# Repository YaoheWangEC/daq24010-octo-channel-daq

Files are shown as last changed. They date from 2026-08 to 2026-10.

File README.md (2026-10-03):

# DAQ24010 — 8 通道通用采集卡

> Octo-Channel Universal DAQ Card



---

## 简介 | Introduction

DAQ24010 是一款基于 **AT32F415** 的 8:1 通道通用采集卡，设计采集范围 ±5 V，前端搭配 12-bit 8 通道 ADC XADC128S022，支持通过 RS485 以 [Linux CLI 风味命令](https://github.com/YaoheWangEC/linux-cli-style-command-driver-framework) 控制采集，也可通过板载按键与 1.8" LCD 本地操作、显示波形。

该采集卡采样率支持 1 k ~ 200 k SPS，提供软件 / 电平 / 斜率触发方式，内置 TL431 基准实时反推 AVDD 用于电压换算。设备同时提供 EEPROM 供上位机持久化通道校正参数。

DAQ24010 is an 8:1 channel universal DAQ card based on the **AT32F415**, designed for a ±5 V acquisition range. With a 12-bit 8-channel ADC XADC128S022 on the front end, it is controlled over RS485 using [Linux CLI-style commands](https://github.com/YaoheWangEC/linux-cli-style-command-driver-framework), and can also be operated locally via on-board keys with waveform display on a 1.8" LCD.

The card supports 1 k ~ 200 k SPS and software / level / slope triggers, and features an on-board TL431 reference that derives AVDD at runtime for voltage conversion. An EEPROM lets the host persist per-channel calibration.

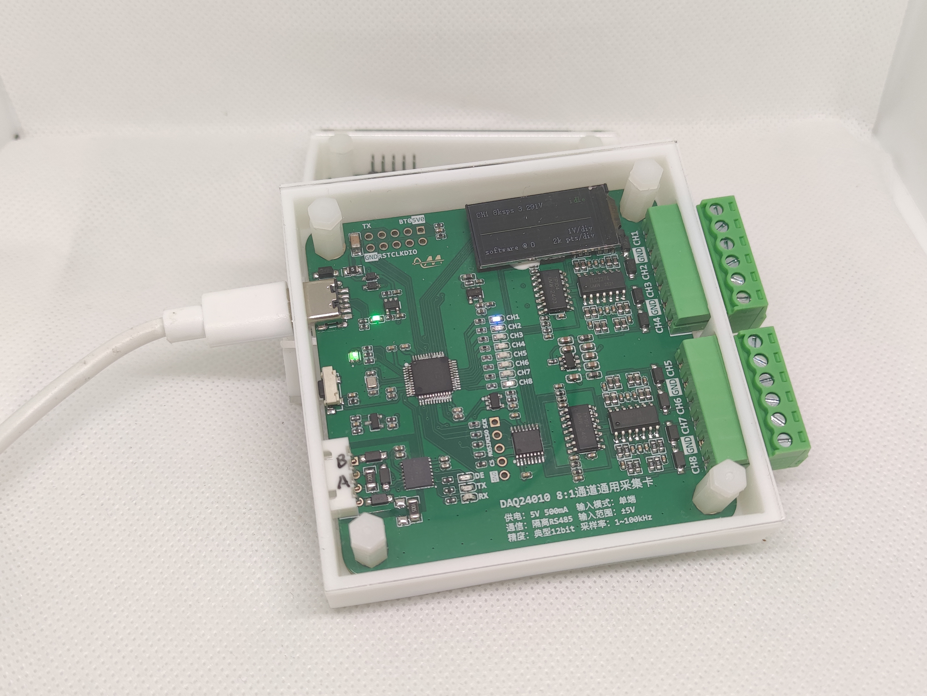
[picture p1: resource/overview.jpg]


> 视频演示：*待补充* ｜ 立创开源：*待补充*

## 主要参数 | Specifications

| 参数 | 值 | 备注 |
| --- | --- | --- |
| 供电 | USB 5 V，max. 500 mA | — |
| 输入通道 | 8 路单端 | 逻辑通道 1~8，可命令切换 |
| 输入范围 | 设计 ±5 V | 极限约 ±6.6 V |
| 采样率 | 1 k ~ 200 k SPS | 原始 100 k / 120 k / 200 k，N 档箱式平均降采样 |
| 触发 | 软件 / 电平 / 斜率 | `software`、`level±`、`slope±`，基于降采样输出 |
| 通信接口 | RS485 | 115200 8N1 |

---

## 快速上手 | Getting Started

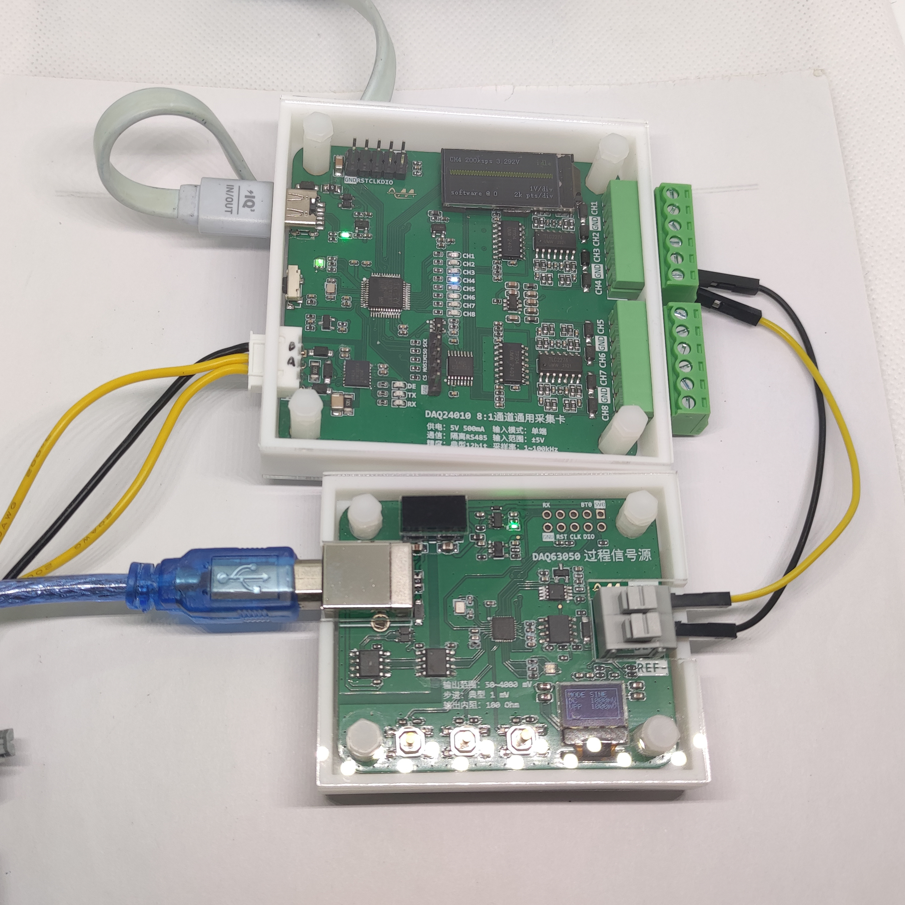
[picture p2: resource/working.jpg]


> 图中为 DAQ24010（待测）与 DAQ63050（信号源）联合测试场景。

### 1. 接线 | Wiring

| 接口名 | 接口形态 | 功能 | 备注 |
| --- | --- | --- | --- |
| 模拟输入 | 3.96 mm 间距插拔式接线端子 | 8 通道电压输入 | 单端，范围约 ±6.6 V |
| RS485 | XH254 4P | 控制 + 数据 | 115200 8N1，A/B 差分 |
| 供电 | USB Type-C | 电源输入 | 5 V，max. 500 mA |

### 2. 上电 | Power On

接通电源后，LCD 显示自检画面（设备名 / 产品名 / UID / `Hello World`），随后进入状态界面。上电约 1 s 后自动执行一次按键触发型采样并显示一次波形。RGB LED 指示采集状态：**空闲-绿 / 等待触发-蓝 / 采集中-红**。

### 3. 本地操作 | Local Control

| 按键 | 短按 | 长按 |
| --- | --- | --- |
| KEY | 软件触发一次采集并显示波形 | 切换下一通道（强制停止当前采集并重采） |

- 波形区：160 列 min/max 包络（前 8000 点，每列 50 点），网格为时间 2k pts/div、电压 1V/div。
- 状态栏显示：当前通道 / 采样率 / AVDD / 触发模式与阈值 / 采集状态。

### 4. RS485 控制 | RS485 Control

串口参数：**115200 bps, 8 data bits, 1 stop bit, no parity**

上电后发送 `lscmd` 可列出所有命令。DAQ24010 采用 [Linux CLI 风格](https://github.com/YaoheWangEC/linux-cli-style-command-driver-framework) 的 ASCII 文本协议，命令以 `\r\n` 结束，响应同样以 `\r\n` 结束，一问一答。

> 采样码值为 12-bit（`adc read` 以 4 字符紧凑 hex 回传，无分隔）。配置类命令（`status channel/rate/trigger`）仅允许在 **IDLE** 状态下执行，否则返回 `ERR: busy`。

#### 命令参考 | Command Reference

**`lscmd`** — 列出所有已注册命令

| 参数 | 说明 |
| --- | --- |
| `-h`, `--help` | 显示帮助 |

```
> lscmd
Supported commands:
  lscmd
  echo
  device
  eeprom
  reboot
  status
  adc
```

**`echo`** — 回显参数，用于测试通信链路

| 参数 | 说明 |
| --- | --- |
| `<text>` | 任意文本，多参数以空格拼接 |

```
> echo hello world
hello world
```

**`device`** — 读取设备名称与 MCU 96-bit 唯一 ID

无参数。

```
> device
Name  : DAQ24010 octo-channel-universal-daq
UID   : 12345678ABCDEF0012345678
```

**`reboot`** — 强制复位（拉低 NRST）

无参数。执行成功设备立即复位，无回包。

**`eeprom`** — 读写 AT24C02（256 B）

| 参数 | 说明 |
| --- | --- |
| `read <addr> [len]` | 读 `len` 字节（默认 1，上限 16），`addr+len ≤ 256` |
| `write <addr> <hex>` | 写紧凑 hex（偶数长度，上限 4 字节） |

```
> eeprom read 0 4
3F800000
> eeprom write 0 3F800000
OK
```

**`status`** — 查询或修改运行配置（修改仅 IDLE）

| 参数 | 说明 |
| --- | --- |
| *(无)* | 全量展示 tick/channel/raw_rate/dec_rate/trigger/state/avdd |
| `<field>` | 单项查询：`tick channel raw_rate rate trigger state avdd` |
| `channel <1..8>` | 设置逻辑通道 |
| `rate <rate>` | 设置降采样率（1000/2000/3000/4000/5000/6000/8000/10000/20000/30000/40000/50000/60000/100000/120000/200000） |
| `trigger <mode> [thr]` | 设置触发（`software level+ level- slope+ slope-`）与阈值码字 |

```
> status
tick     : 12345
channel  : 1
raw_rate : 200000
dec_rate : 8000
trigger  : software @ 0
state    : idle
avdd     : 3.291
> status channel 2
channel  : 2
> status rate 10000
raw_rate : 200000
dec_rate : 10000
```

**`adc`** — 采集控制与数据流

| 参数 | 说明 |
| --- | --- |
| *(无)* | 配置全量展示 + ringbuf 信息（buf_cnt/buf_cap/buf_full/overflow） |
| `status` | 仅返回采集状态（便于自动化读取） |
| `start` / `stop` | 开始 / 强制停止采集（stop 保留 ringbuf） |
| `rest` | 仅返回剩余样本数（便于轮询） |
| `read [n]` | 读出至多 n 个样本（默认/上限 128），4 字符紧凑 hex；不足则返回已有数据 |

```
> adc start
OK
> adc rest
1024
> adc read 128
0ABC0ABD0ABE...   # 每样本 4 hex 字符
```

> **采集模型**：设备采样写入 8192 点环形缓冲，**写满即自动停止**（不循环覆盖）。上位机需轮询 `adc rest` / `adc read` 排空。

---

## Python 驱动 | Python Driver

`software/driver/` 下提供纯驱动库 `daq24010.py`，封装上述 RS485 命令协议，内置电压换算、按通道校正与 EEPROM 持久化。

### 依赖 | Requirements

- Python 3.10+
- `pyserial`、`numpy`（自检绘图另需 `matplotlib`）

```
pip install pyserial numpy matplotlib
```

### 快速开始 | Quick Start

```python
from daq24010 import DAQ24010

with DAQ24010() as dev:                 # 自动嗅探串口（也可 DAQ24010('COM5')）
    print(dev.get_device_name(), dev.get_uid())

    dev.set_channel(1)
    dev.set_rate(2000)
    dev.set_trigger('level+', 0.0)      # 0V 电平上升沿触发（阈值单位: V）
    v = dev.capture(2000, timeout=5.0)  # 一键采集 2000 点, 返回电压 np.ndarray

# with 退出时 close(): 默认发 reboot 复位设备
```

### API 速查 | API Overview

| 区域 | 方法 |
| --- | --- |
| 生命周期 | `__init__(port=None, load_calib=True)` / `close(reboot=True)` / `with` |
| 设备信息 | `get_device_name()` / `get_uid()` |
| 状态查询 | `get_avdd()` / `get_status()` |
| 配置（仅 IDLE） | `set_channel`/`get_channel`、`set_rate`/`get_rate`、`set_trigger`/`get_trigger` |
| 采集控制 | `start` / `stop` / `get_state` / `get_acq_info` / `remaining` |
| 数据面 | `stream_read(n=128)` / `capture(n, timeout=5.0)` |
| 持久化 | `eeprom_read(addr, length)` / `eeprom_write(addr, data)` |
| 其他 | `reboot()` |

> 驱动对外以 **V** 为单位收发，内部换算为 ADC 码值。电压换算与校正、EEPROM 布局、采集吞吐等详细说明见 [`software/driver/README.md`](software/driver/README.md)。

---

## 许可证 | License

本项目由不同许可的组件构成：

- **应用代码**（`software/daq2401x-octo-channel-daq-f415cbt7/project/MDK_V5/daq2401x/` 下用户编写的采集逻辑、命令框架、LCD / 按键驱动等，以及 `software/driver/` 的 Python 驱动）以 [MIT License](LICENSE) 发布，版权归 [YaoheWangEC](https://github.com/YaoheWangEC)。
- **Artery BSP**（`libraries/drivers/`、`project/src/` 中 `wk_*.c`、`main.c` 模板等）版权归 Artery Technology，允许在与 Artery MCU 配合使用的场合复制和分发。
- **CMSIS-Core** 版权归 Arm Limited，遵循 Apache License 2.0。

This project consists of components under different licenses:

- **Application code** (user-written acquisition logic, command framework, LCD / key drivers under `software/daq2401x-octo-channel-daq-f415cbt7/project/MDK_V5/daq2401x/`, and the Python driver under `software/driver/`) is released under the [MIT License](LICENSE), copyright [YaoheWangEC](https://github.com/YaoheWangEC).
- **Artery BSP** (`libraries/drivers/`, `project/src/` `wk_*.c`, `main.c` template, etc.) is copyright Artery Technology, with permission to copy and distribute for use with Artery MCUs.
- **CMSIS-Core** is copyright Arm Limited under Apache License 2.0.

## 资助致谢 | Sponsorship Acknowledgment

感谢梁总的百亿 Token 补贴政策，使本项目的 AI 辅助开发成本趋近于零。

## 致谢 | Acknowledgements

本项目由 [YaoheWangEC](https://github.com/YaoheWangEC) 设计开发。在项目开发与开源文档整理过程中，DeepSeek 提供了大量的辅助，包括代码编写、设计建议和文档组织。

## 免责声明 | Disclaimer

本项目由 DeepSeek 辅助编写，可能存在纰漏。本项目仅供学习研究，未经工业场景充分验证。使用者应自行评估安全风险，作者与 DeepSeek 不对因使用本项目及其文档所造成的任何损失承担责任。

This documentation was drafted with the assistance of DeepSeek and may contain errors. This project is provided for educational and research purposes only and has not been fully validated for industrial environments. Users should evaluate safety risks on their own. The author and DeepSeek assume no liability for any damages arising from the use of this project or its documentation.

---

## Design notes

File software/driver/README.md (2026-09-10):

# DAQ24010 Python 驱动

DAQ24010 八通道通用采集卡（AT32F415 + XADC128S022，RS485 命令面）的 Python 上位机驱动。

## 文件

| 文件 | 说明 |
|---|---|
| `daq24010.py` | 驱动主体（`DAQ24010` 类） + `__main__` 冒烟自检 |
| `write_calib.py` | 向 EEPROM 写入 8 通道一阶校正参数 |

## 依赖

- Python 3.10+（使用 `X | None` 类型标注）
- `pyserial`、`numpy`；自检绘图另需 `matplotlib`

```
pip install pyserial numpy matplotlib
```

## 快速开始

```python
from daq24010 import DAQ24010

with DAQ24010() as dev:                 # 自动嗅探串口（也可 DAQ24010('COM5')）
    print(dev.get_device_name(), dev.get_uid())

    dev.set_channel(1)
    dev.set_rate(2000)
    dev.set_trigger('level+', 0.0)      # 0V 电平上升沿触发（阈值单位: V）
    v = dev.capture(2000, timeout=5.0)  # 一键采集 2000 点, 返回电压 np.ndarray

# with 退出时 close(): 默认发 reboot 复位设备
```

连续采集（自行控制启停）：

```python
dev.start()
try:
    while ...:
        chunk = dev.stream_read(128)    # 单次取数, 返回电压数组（可能为空）
finally:
    dev.stop()
```

## API 速查

| 区域 | 方法 |
|---|---|
| 生命周期 | `__init__(port=None, load_calib=True)` / `close(reboot=True)` / `with` |
| 设备信息 | `get_device_name()` / `get_uid()` |
| 状态查询 | `get_avdd()` / `get_status()` |
| 配置（仅 IDLE） | `set_channel`/`get_channel`、`set_rate`/`get_rate`、`set_trigger`/`get_trigger` |
| 采集控制 | `start` / `stop` / `get_state` / `get_acq_info` / `remaining` |
| 数据面 | `stream_read(n=128)` / `capture(n, timeout=5.0)` |
| 持久化 | `eeprom_read(addr, length)` / `eeprom_write(addr, data)` |
| 其他 | `reboot()` |

## 采集模型与吞吐

- 设备采集写入 **8192 点环形缓冲**，**写满即自动停止**（不循环覆盖）；主机需轮询 `stream_read` 排空。
- 115200 + 4 hex 字符/样本 → 连续吞吐上限约 **2.7~2.88 kSPS**。
  - **rate ≤ ~2.5k**：主机排空快于采样 → 可长时间连续采集。
  - **rate > ~2.8k**：环很快填满自停 → 只能“突发捕获”最多 8192 点后再读出。
- `capture(n)` 的循环天然兼容两种模式；取不满 n 抛 `RuntimeError`（不返回短数据）。
- 协议无样本序号/CRC，无法验证连续性。

## 触发

- 模式：`software` / `level+` / `level-` / `slope+` / `slope-`（`TRIGGER_MODES`）。
- `set_trigger(mode, threshold)` 的 `threshold` 为**电压 V**；`level±` 为电平、`slope±` 为相邻样本差值幅度。
- 判定基于降采样后的输出样本（2 点窗口）。
- `level±` / `slope±` 属硬件触发，已上板实测。
- 固件无触发超时；等待触发时 `stream_read` 返回空数组，`capture` 需给足 `timeout`。

## 电压换算与校正

硬件链路：输入经衰减/抬升后进 ADC（满量程 0~AVDD），换算回输入：

```
V_adc = code × AVDD / 4096
V_in  = calib_k × (4 × V_adc − 2 × AVDD) + calib_b     # 满量程约 ±2·AVDD (≈ ±6.6V)
```

- AVDD 由 TL431 基准实时反推（`get_avdd`）。
- 校正按**通道**生效：初始化时从 EEPROM 自动载入 8 通道 `(calib_k, calib_b)`；换算时按当前所选通道自动套用。
- 范围校验：`|k| ≤ 2`、`|b| ≤ 5`；越界或读取失败在构造时抛 `RuntimeError`。

### EEPROM 校正布局（从地址 0 起，每通道 8 字节，小端 float32）

| 偏移 | 内容 |
|---|---|
| `ch*8 + 0` | `calib_k` (float32) |
| `ch*8 + 4` | `calib_b` (float32) |

写入（默认 1/0；实际校准后改 `write_calib.py` 的 `CALIB` 表重跑）：

```
python write_calib.py
```

> 空 EEPROM 会解出 NaN 导致构造失败，脚本用 `DAQ24010(load_calib=False)` 绕过校验完成引导写入。

## 命令协议速查

命令以 `\r\n` 结尾，一问一答，ASCII。错误响应以 `ERR:` / `Unknown command:` / `Invalid ` / `Usage:` 开头（驱动统一转 `RuntimeError`）。

| 命令 | 说明 |
|---|---|
| `device` | 设备名 + UID |
| `status` / `status <field>` / `status channel\|rate\|trigger <v>` | 配置/状态查询与修改（改仅 IDLE） |
| `adc` / `adc status\|start\|stop\|rest\|read [n]` | 采集控制与数据读取 |
| `eeprom read <addr> [len]` / `eeprom write <addr> <hex>` | EEPROM 读写 |
| `reboot` | 强制复位（成功无回包） |

## 自检

```
python daq24010.py
```

覆盖设备信息、状态、配置、采集控制、数据面（突发/触发/连续/频谱）、EEPROM、`_send` 收帧与错误判定。需连接硬件；会改写 EEPROM 末尾 16 字节。

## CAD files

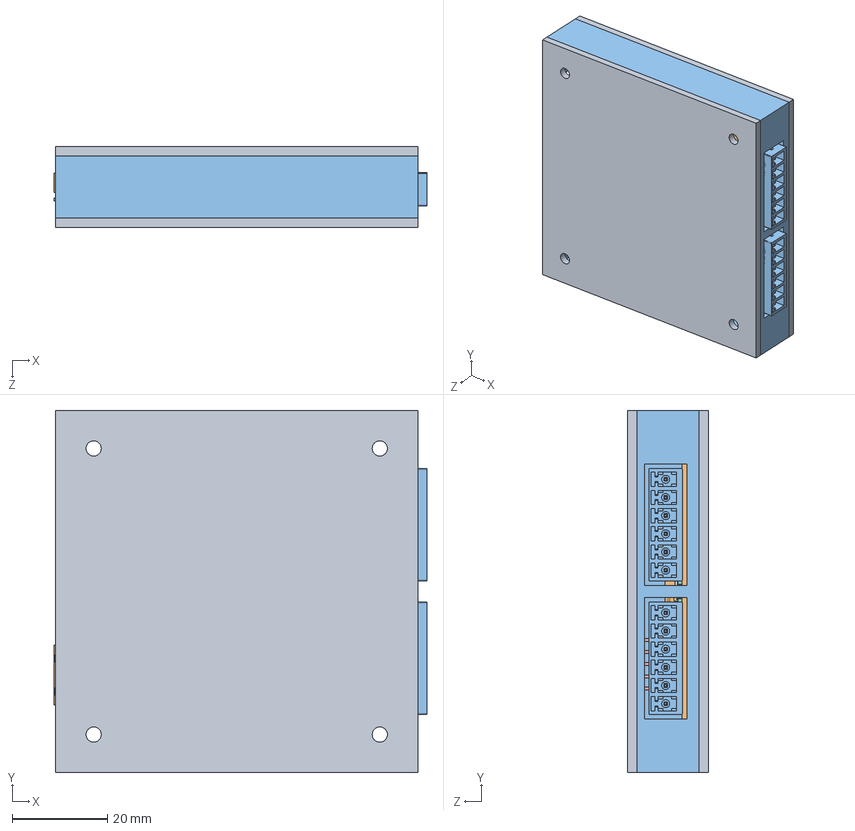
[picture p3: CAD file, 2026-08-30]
mechanical/daq.SLDASM
78.2 x 76.0 x 17.0 mm
CONN-TH_4P-P2.50_WAFER-XH254WZ-4AM~CONN-TH_4P-P2.50_WAFER-XH254WZ-4AM~ACol.step
CONN-TH_6P-P3.81_KF2EDGR-3.81-6P~CONN-TH_6P-P3.81_KF2EDGR-3.81-6P~N3mf.step x 2
2x5P___________________~HDR2.54-M-LI-2X5P~wjJB.step
HDR-TH_5P-P2.54-V-M~HDR-TH_5P-P2.54-M-LI-1X5P~YeT6.step
LGA-16_L5.2-W4.7-P0.65-TL_CA-IS2062A-FRANK2~LGA-16_L5.2-W4.7-P0.65-TL_CA-IS2062A-FRANK2~Jhdr.step
SOT-23-5_L2.9-W1.6-P0.95-LS2.8-BR~SOT-23-5_L2.9-W1.6-P0.95-LS2.8-BR~UHvK.step x 3
SOP-14_L8.7-W3.9-P1.24-LS6.0-BL~SOP-14_L8.8-W3.9-P1.27-LS6.0-BL~Tf3m.step x 4
LED-SMD_4P-L1.6-W1.5-BL-2~LED-SMD_4P-L1.6-W1.5-BL-2~zMsI.step
SW-SMD_SHOU_TS36CA-0.6~SW-SMD_SHOU_TS36CA-0.6~DG2b.step
TYPE-C-SMD_TYPE-C-31-M-16~TYPE-C-SMD_6P-L8.9-W6.8-H3.2-P1.00~Sp7n.step
TSSOP-16_L5.0-W4.4-P0.65-LS6.4-BL~TSSOP-16_L5.0-W4.4-H1.0-LS6.4-P0.65~OMuv.step
SOT-23-3_L3.0-W1.7-P0.95-LS2.9-BR~SOT-23-3P_L2.9-W1.3-H1.0-LS2.4-P0.95~GGwT.step
CRYSTAL-SMD_4P-L2.0-W1.6-BL-A~CRYSTAL-SMD_4P-L2.0-W1.6-BL-A~iUgL.step
SOT-23-6_L2.9-W1.6-P0.95-LS2.8-BR~SOT-23-6_L2.9-W1.6-H1.5-LS2.8-P0.95~HMpz.step
C0603~C0603_L1.6-W0.8-H0.8~UTJ7.step x 6
LQFP-48_L7.0-W7.0-P0.50-LS9.0-BL~LQFP-48_L7.0-W7.0-H1.4-LS9.0-P0.50~c4TP.step
Board~sWdV.step
plate x 2

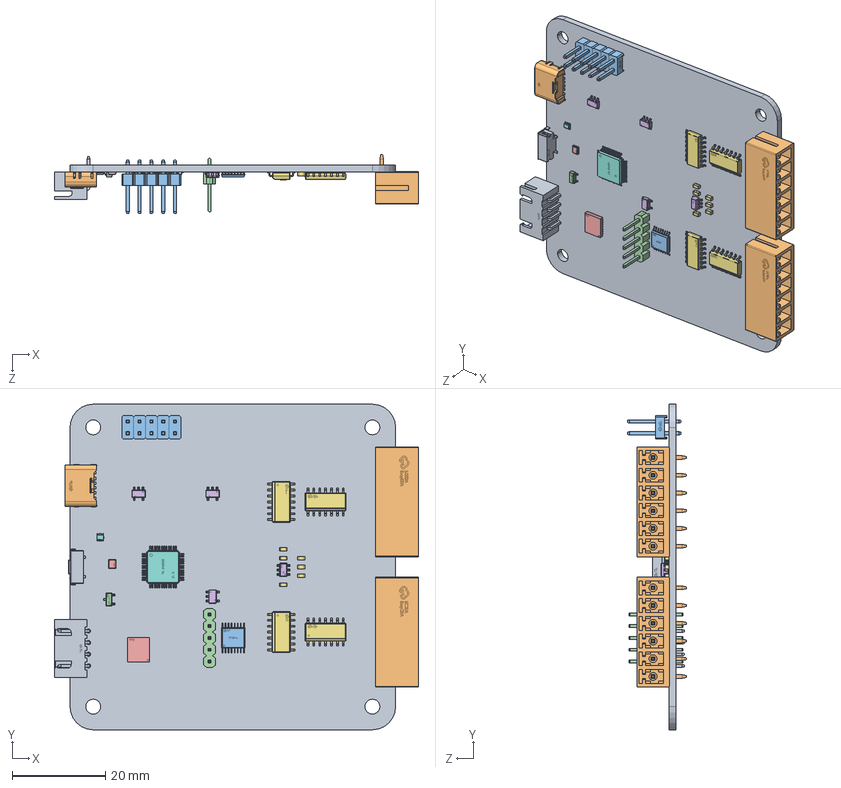
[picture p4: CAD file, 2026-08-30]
mechanical/PCBA_Simplified.SLDASM
78.2 x 70.0 x 12.7 mm
CONN-TH_4P-P2.50_WAFER-XH254WZ-4AM~CONN-TH_4P-P2.50_WAFER-XH254WZ-4AM~ACol.step
CONN-TH_6P-P3.81_KF2EDGR-3.81-6P~CONN-TH_6P-P3.81_KF2EDGR-3.81-6P~N3mf.step x 2
2x5P___________________~HDR2.54-M-LI-2X5P~wjJB.step
HDR-TH_5P-P2.54-V-M~HDR-TH_5P-P2.54-M-LI-1X5P~YeT6.step
LGA-16_L5.2-W4.7-P0.65-TL_CA-IS2062A-FRANK2~LGA-16_L5.2-W4.7-P0.65-TL_CA-IS2062A-FRANK2~Jhdr.step
SOT-23-5_L2.9-W1.6-P0.95-LS2.8-BR~SOT-23-5_L2.9-W1.6-P0.95-LS2.8-BR~UHvK.step x 3
SOP-14_L8.7-W3.9-P1.24-LS6.0-BL~SOP-14_L8.8-W3.9-P1.27-LS6.0-BL~Tf3m.step x 4
LED-SMD_4P-L1.6-W1.5-BL-2~LED-SMD_4P-L1.6-W1.5-BL-2~zMsI.step
SW-SMD_SHOU_TS36CA-0.6~SW-SMD_SHOU_TS36CA-0.6~DG2b.step
TYPE-C-SMD_TYPE-C-31-M-16~TYPE-C-SMD_6P-L8.9-W6.8-H3.2-P1.00~Sp7n.step
TSSOP-16_L5.0-W4.4-P0.65-LS6.4-BL~TSSOP-16_L5.0-W4.4-H1.0-LS6.4-P0.65~OMuv.step
SOT-23-3_L3.0-W1.7-P0.95-LS2.9-BR~SOT-23-3P_L2.9-W1.3-H1.0-LS2.4-P0.95~GGwT.step
CRYSTAL-SMD_4P-L2.0-W1.6-BL-A~CRYSTAL-SMD_4P-L2.0-W1.6-BL-A~iUgL.step
SOT-23-6_L2.9-W1.6-P0.95-LS2.8-BR~SOT-23-6_L2.9-W1.6-H1.5-LS2.8-P0.95~HMpz.step
C0603~C0603_L1.6-W0.8-H0.8~UTJ7.step x 6
LQFP-48_L7.0-W7.0-P0.50-LS9.0-BL~LQFP-48_L7.0-W7.0-H1.4-LS9.0-P0.50~c4TP.step
Board~sWdV.step

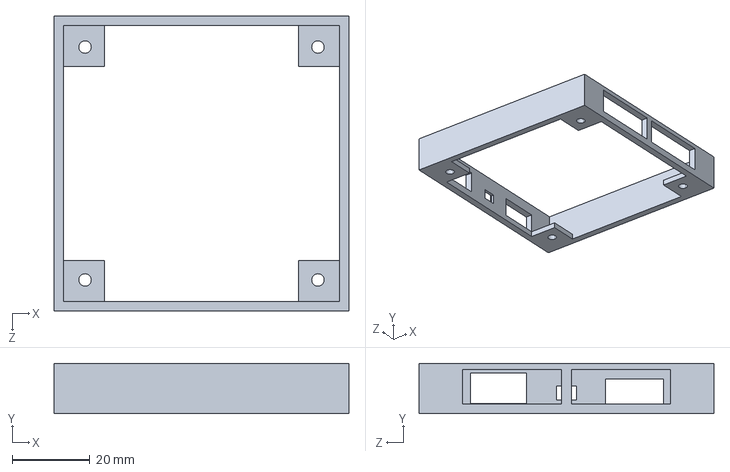
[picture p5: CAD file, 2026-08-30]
mechanical/box.STEP
76.0 x 13.0 x 76.0 mm

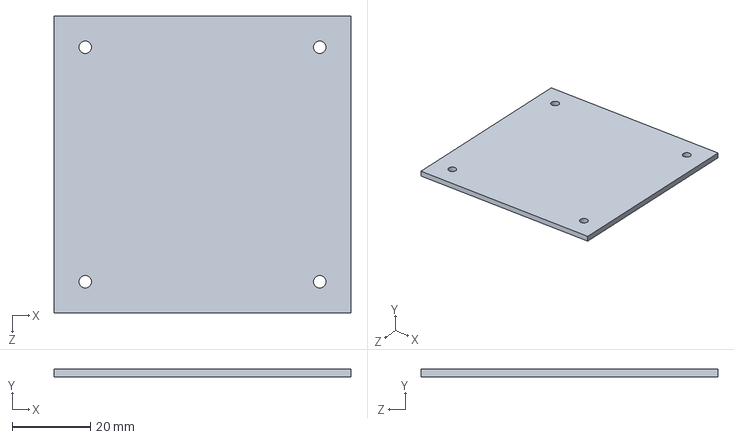
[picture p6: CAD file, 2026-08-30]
mechanical/plate.SLDPRT
76.0 x 2.00 x 76.0 mm

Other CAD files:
mechanical/box.SLDPRT
mechanical/plate.DWG

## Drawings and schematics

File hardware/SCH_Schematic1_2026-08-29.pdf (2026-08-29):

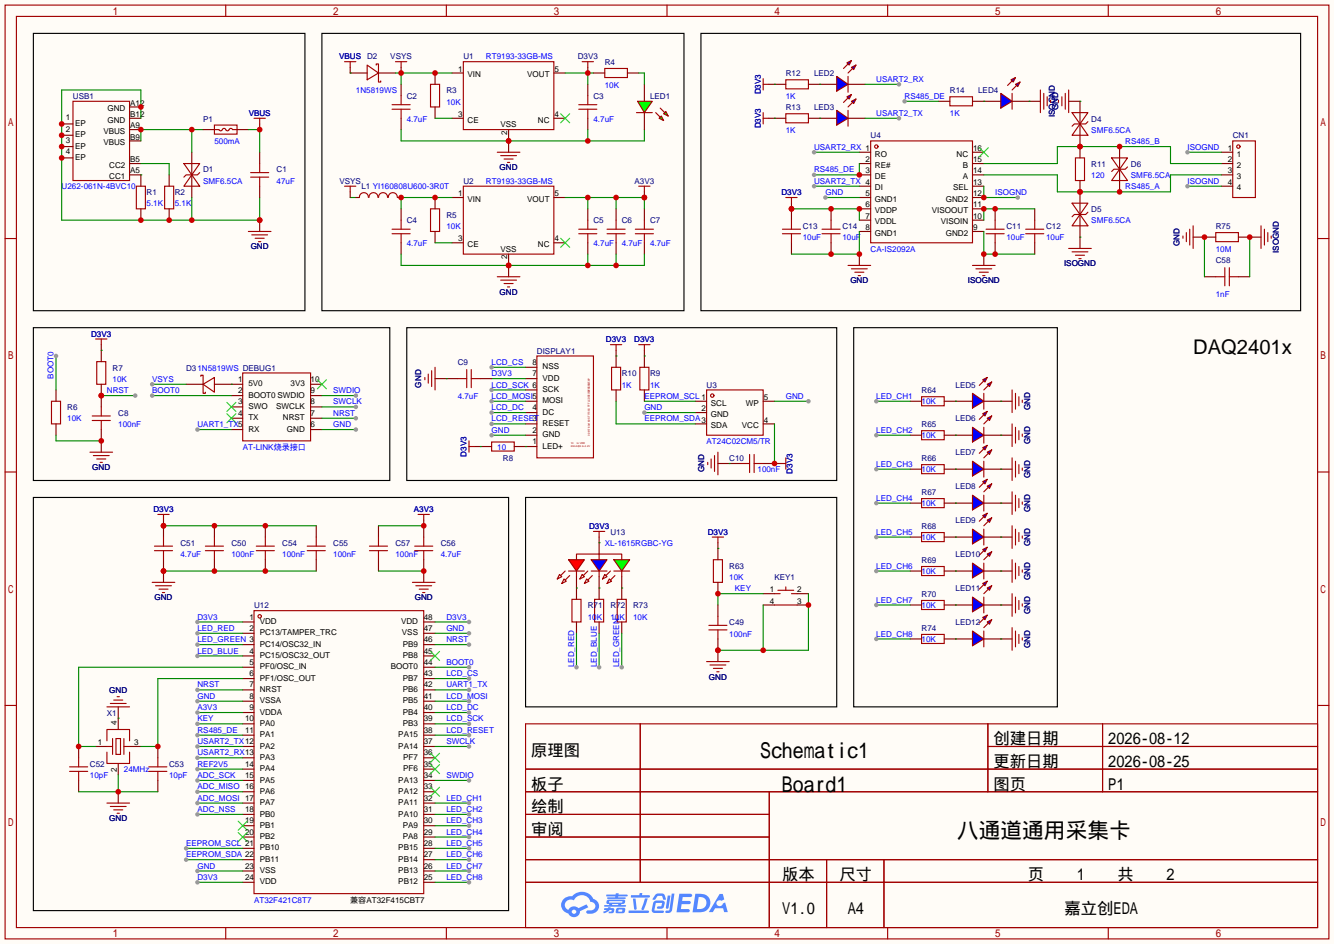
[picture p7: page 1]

GND GND GND GND

更新日期 | 2026-08-25

板子 | Board1 | 图页 | P1
绘制 | | 八通道通用采集卡
审阅

V1.0 | A4 | 嘉立创EDA

# IN6 10 IN7 11 DGND 12 VD 13 DIN 14 DOUT 15 SCLK 16

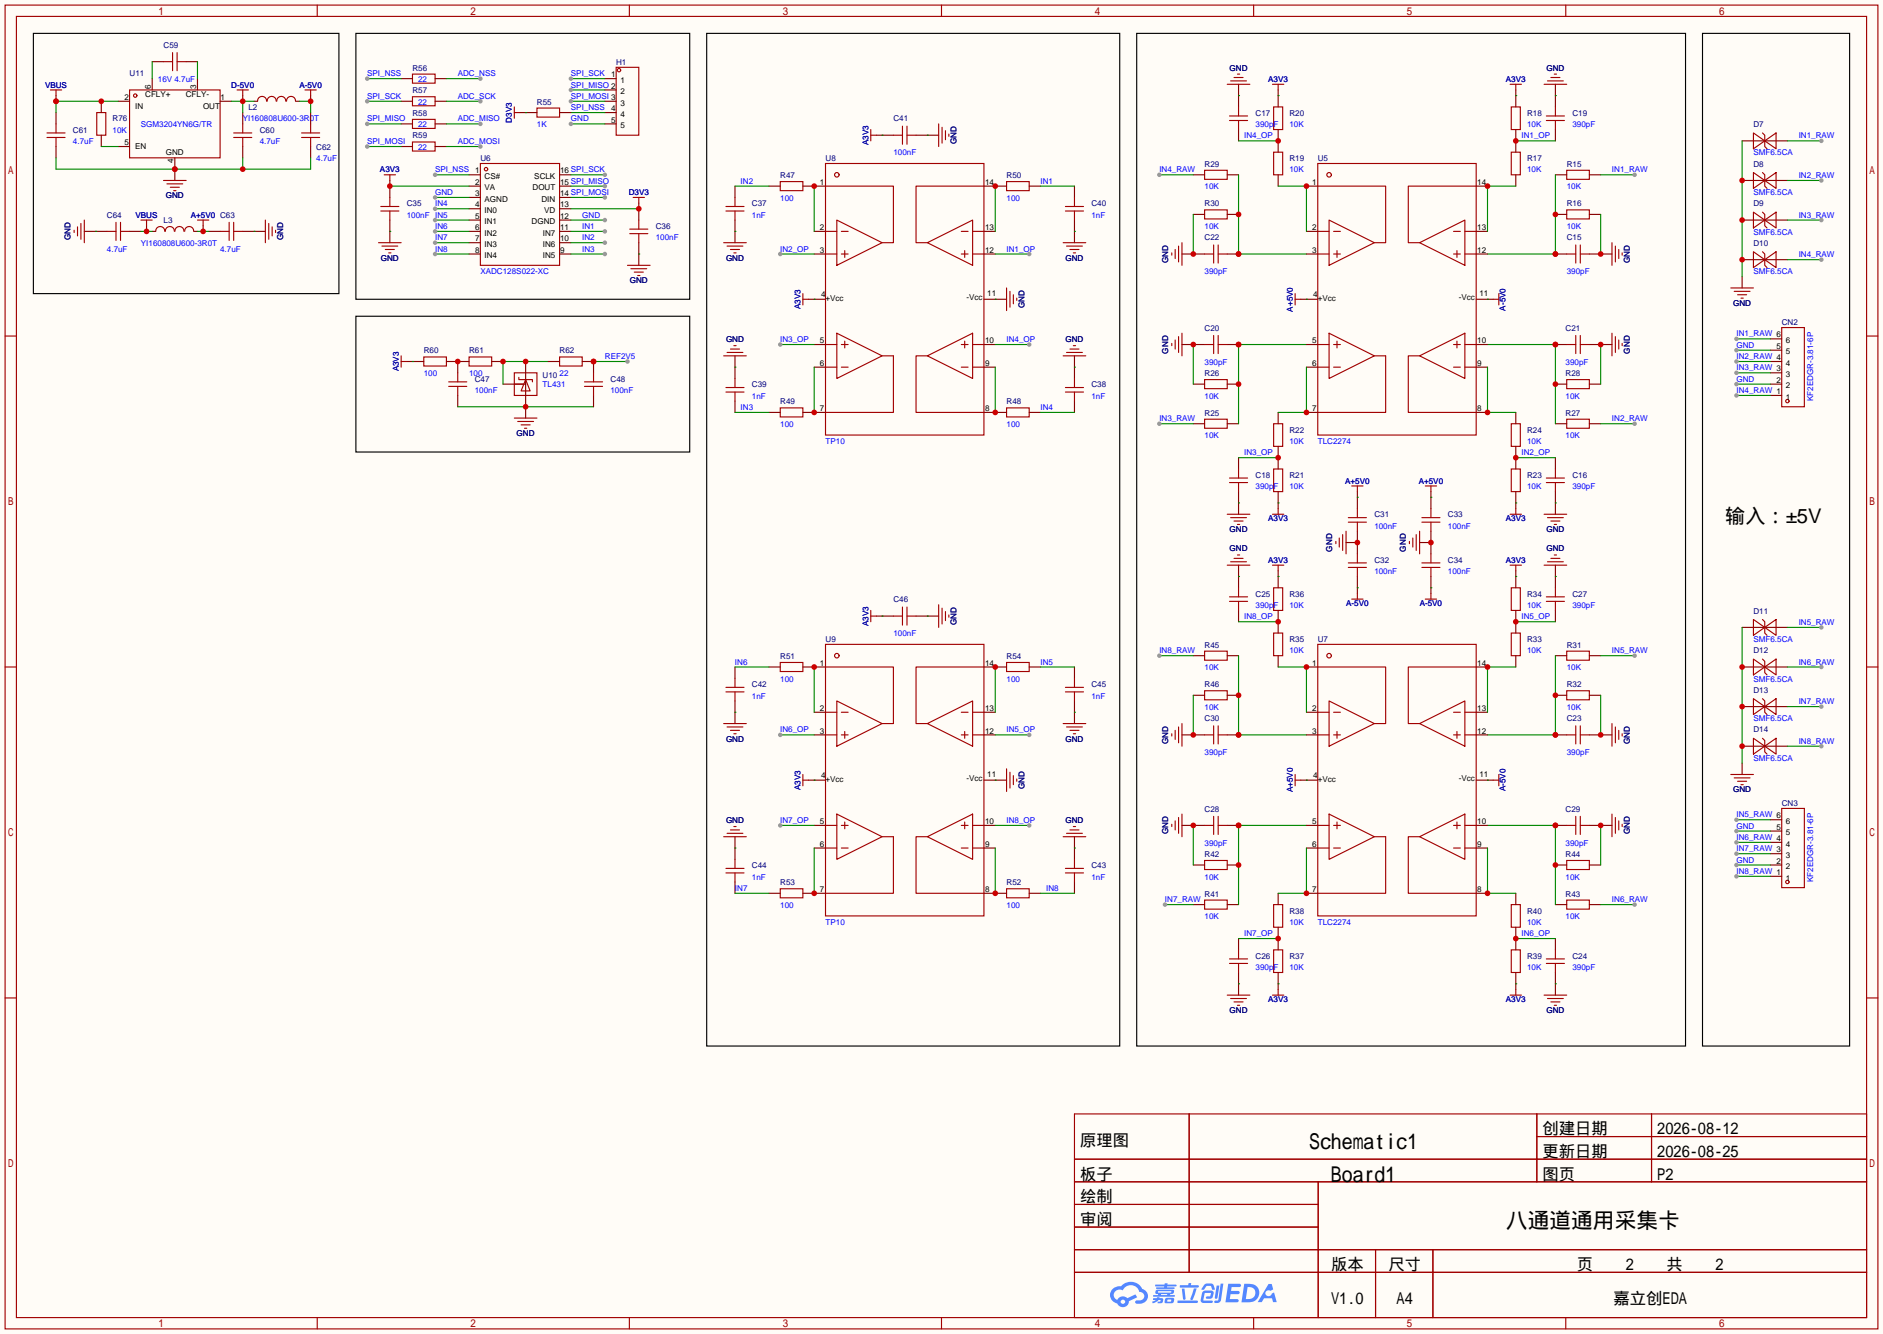
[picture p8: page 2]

原理图 | Schematic1 | 创建日期 | 2026-08-12

更新日期 | 2026-08-25

板子 | Board1 | 图页 | P2
绘制 | | 八通道通用采集卡
审阅

V1.0 | A4 | 嘉立创EDA

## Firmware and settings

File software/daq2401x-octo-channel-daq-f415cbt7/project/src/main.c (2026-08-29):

/* add user code begin Header */
/**
  **************************************************************************
  * @file     main.c
  * @brief    main program
  **************************************************************************
  * Copyright (c) 2025, Artery Technology, All rights reserved.
  *
  * The software Board Support Package (BSP) that is made available to
  * download from Artery official website is the copyrighted work of Artery.
  * Artery authorizes customers to use, copy, and distribute the BSP
  * software and its related documentation for the purpose of design and
  * development in conjunction with Artery microcontrollers. Use of the
  * software is governed by this copyright notice and the following disclaimer.
  *
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
  **************************************************************************
  */
/* add user code end Header */

/* Includes ------------------------------------------------------------------*/
#include "at32f415_wk_config.h"
#include "wk_adc.h"
#include "wk_debug.h"
#include "wk_i2c.h"
#include "wk_spi.h"
#include "wk_tmr.h"
#include "wk_usart.h"
#include "wk_wdt.h"
#include "wk_dma.h"
#include "wk_gpio.h"
#include "wk_system.h"
#include "i2c_app.h"

/* private includes ----------------------------------------------------------*/
/* add user code begin private includes */
#include "user.h"
/* add user code end private includes */

/* private typedef -----------------------------------------------------------*/
/* add user code begin private typedef */

/* add user code end private typedef */

/* private define ------------------------------------------------------------*/
/* add user code begin private define */

/* add user code end private define */

/* private macro -------------------------------------------------------------*/
/* add user code begin private macro */

/* add user code end private macro */

/* private variables ---------------------------------------------------------*/
/* add user code begin private variables */

/* add user code end private variables */

/* private function prototypes --------------------------------------------*/
/* add user code begin function prototypes */

/* add user code end function prototypes */

/* private user code ---------------------------------------------------------*/
/* add user code begin 0 */

/* add user code end 0 */

/**
  * @brief main function.
  * @param  none
  * @retval none
  */
int main(void)
{
  /* add user code begin 1 */

  /* add user code end 1 */

  /* system clock config. */
  wk_system_clock_config();

  /* config periph clock. */
  wk_periph_clock_config();

  /* init debug function. */
  wk_debug_config();

  /* nvic config. */
  wk_nvic_config();

  /* timebase config for
     void wk_delay_us(uint32_t delay);
     void wk_delay_ms(uint32_t delay); */
  wk_timebase_init();

  /* init gpio function. */
  wk_gpio_config();

  /* init adc1 function. */
  wk_adc1_init();

  /* init dma1 channel1 */
  wk_dma1_channel1_init();
  /* config dma channel transfer parameter */
  /* user need to modify define values DMAx_CHANNELy_XXX_BASE_ADDR 
     and DMAx_CHANNELy_BUFFER_SIZE in at32xxx_wk_config.h */
  wk_dma_channel_config(DMA1_CHANNEL1, 
                        (uint32_t)&USART2->dt, 
                        DMA1_CHANNEL1_MEMORY_BASE_ADDR, 
                        DMA1_CHANNEL1_BUFFER_SIZE);
  dma_channel_enable(DMA1_CHANNEL1, TRUE);

  /* init dma1 channel2 */
  wk_dma1_channel2_init();
  /* config dma channel transfer parameter */
  /* user need to modify define values DMAx_CHANNELy_XXX_BASE_ADDR 
     and DMAx_CHANNELy_BUFFER_SIZE in at32xxx_wk_config.h */
  wk_dma_channel_config(DMA1_CHANNEL2, 
                        (uint32_t)&USART2->dt, 
                        DMA1_CHANNEL2_MEMORY_BASE_ADDR, 
                        DMA1_CHANNEL2_BUFFER_SIZE);
  dma_channel_enable(DMA1_CHANNEL2, TRUE);

  /* init dma1 channel3 */
  wk_dma1_channel3_init();
  /* config dma channel transfer parameter */
  /* user need to modify define values DMAx_CHANNELy_XXX_BASE_ADDR 
     and DMAx_CHANNELy_BUFFER_SIZE in at32xxx_wk_config.h */
  wk_dma_channel_config(DMA1_CHANNEL3, 
                        (uint32_t)&SPI1->dt, 
                        DMA1_CHANNEL3_MEMORY_BASE_ADDR, 
                        DMA1_CHANNEL3_BUFFER_SIZE);
  dma_channel_enable(DMA1_CHANNEL3, TRUE);

  /* init dma1 channel4 */
  wk_dma1_channel4_init();
  /* config dma channel transfer parameter */
  /* user need to modify define values DMAx_CHANNELy_XXX_BASE_ADDR 
     and DMAx_CHANNELy_BUFFER_SIZE in at32xxx_wk_config.h */
  wk_dma_channel_config(DMA1_CHANNEL4, 
                        (uint32_t)&TMR3->cval, 
                        DMA1_CHANNEL4_MEMORY_BASE_ADDR, 
                        DMA1_CHANNEL4_BUFFER_SIZE);
  dma_channel_enable(DMA1_CHANNEL4, TRUE);

  /* init usart1 function. */
  wk_usart1_init();

  /* init usart2 function. */
  wk_usart2_init();

  /* init spi1 function. */
  wk_spi1_init();

  /* init spi2 function. */
  wk_spi2_init();

  /* init i2c2 function. */
  wk_i2c2_init();

  /* init tmr3 function. */
  wk_tmr3_init();

  /* init i2c app function. */
  wk_i2c_app_init();

  /* init tmr11 function. */
  wk_tmr11_init();

  /* init dma1 channel5 */
  wk_dma1_channel5_init();
  /* config dma channel transfer parameter */
  /* user need to modify define values DMAx_CHANNELy_XXX_BASE_ADDR 
     and DMAx_CHANNELy_BUFFER_SIZE in at32xxx_wk_config.h */
  wk_dma_channel_config(DMA1_CHANNEL5, 
                        (uint32_t)&SPI2->dt, 
                        DMA1_CHANNEL5_MEMORY_BASE_ADDR, 
                        DMA1_CHANNEL5_BUFFER_SIZE);
  dma_channel_enable(DMA1_CHANNEL5, TRUE);

  /* init dma1 channel6 */
  wk_dma1_channel6_init();
  /* config dma channel transfer parameter */
  /* user need to modify define values DMAx_CHANNELy_XXX_BASE_ADDR 
     and DMAx_CHANNELy_BUFFER_SIZE in at32xxx_wk_config.h */
  wk_dma_channel_config(DMA1_CHANNEL6, 
                        (uint32_t)&ADC1->odt, 
                        DMA1_CHANNEL6_MEMORY_BASE_ADDR, 
                        DMA1_CHANNEL6_BUFFER_SIZE);
  dma_channel_enable(DMA1_CHANNEL6, TRUE);

  /* init wdt function. */
  wk_wdt_init();

  /* add user code begin 2 */
  setup();
  /* add user code end 2 */

  while(1)
  {
    /* add user code begin 3 */
    loop();
    /* add user code end 3 */
  }
}

  /* add user code begin 4 */

  /* add user code end 4 */

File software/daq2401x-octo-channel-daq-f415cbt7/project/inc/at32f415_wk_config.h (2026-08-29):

/* add user code begin Header */
/**
  **************************************************************************
  * @file     at32f415_wk_config.h
  * @brief    header file of work bench config
  **************************************************************************
  * Copyright (c) 2025, Artery Technology, All rights reserved.
  *
  * The software Board Support Package (BSP) that is made available to
  * download from Artery official website is the copyrighted work of Artery.
  * Artery authorizes customers to use, copy, and distribute the BSP
  * software and its related documentation for the purpose of design and
  * development in conjunction with Artery microcontrollers. Use of the
  * software is governed by this copyright notice and the following disclaimer.
  *
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
  **************************************************************************
  */
/* add user code end Header */

/* define to prevent recursive inclusion -----------------------------------*/
#ifndef __AT32F415_WK_CONFIG_H
#define __AT32F415_WK_CONFIG_H

#ifdef __cplusplus
extern "C" {
#endif

/* includes -----------------------------------------------------------------------*/
#include "stdio.h"
#include "at32f415.h"

/* private includes -------------------------------------------------------------*/
/* add user code begin private includes */

/* add user code end private includes */

/* exported types -------------------------------------------------------------*/
/* add user code begin exported types */

/* add user code end exported types */

/* exported constants --------------------------------------------------------*/
/* add user code begin exported constants */

/* add user code end exported constants */

/* exported macro ------------------------------------------------------------*/
/* add user code begin exported macro */

/* add user code end exported macro */

/* add user code begin dma define */
/* user can only modify the dma define value */
#define DMA1_CHANNEL1_BUFFER_SIZE   0
#define DMA1_CHANNEL1_MEMORY_BASE_ADDR   0
//#define DMA1_CHANNEL1_PERIPHERAL_BASE_ADDR  0

#define DMA1_CHANNEL2_BUFFER_SIZE   0
#define DMA1_CHANNEL2_MEMORY_BASE_ADDR   0
//#define DMA1_CHANNEL2_PERIPHERAL_BASE_ADDR   0

#define DMA1_CHANNEL3_BUFFER_SIZE   0
#define DMA1_CHANNEL3_MEMORY_BASE_ADDR   0
//#define DMA1_CHANNEL3_PERIPHERAL_BASE_ADDR   0

#define DMA1_CHANNEL4_BUFFER_SIZE   0
#define DMA1_CHANNEL4_MEMORY_BASE_ADDR   0
//#define DMA1_CHANNEL4_PERIPHERAL_BASE_ADDR   0

#define DMA1_CHANNEL5_BUFFER_SIZE   0
#define DMA1_CHANNEL5_MEMORY_BASE_ADDR   0
//#define DMA1_CHANNEL5_PERIPHERAL_BASE_ADDR   0

#define DMA1_CHANNEL6_BUFFER_SIZE   0
#define DMA1_CHANNEL6_MEMORY_BASE_ADDR   0
//#define DMA1_CHANNEL6_PERIPHERAL_BASE_ADDR   0

//#define DMA1_CHANNEL7_BUFFER_SIZE   0
//#define DMA1_CHANNEL7_MEMORY_BASE_ADDR   0
//#define DMA1_CHANNEL7_PERIPHERAL_BASE_ADDR   0

//#define DMA2_CHANNEL1_BUFFER_SIZE   0
//#define DMA2_CHANNEL1_MEMORY_BASE_ADDR   0
//#define DMA2_CHANNEL1_PERIPHERAL_BASE_ADDR   0

//#define DMA2_CHANNEL2_BUFFER_SIZE   0
//#define DMA2_CHANNEL2_MEMORY_BASE_ADDR   0
//#define DMA2_CHANNEL2_PERIPHERAL_BASE_ADDR   0

//#define DMA2_CHANNEL3_BUFFER_SIZE   0
//#define DMA2_CHANNEL3_MEMORY_BASE_ADDR   0
//#define DMA2_CHANNEL3_PERIPHERAL_BASE_ADDR   0

//#define DMA2_CHANNEL4_BUFFER_SIZE   0
//#define DMA2_CHANNEL4_MEMORY_BASE_ADDR   0
//#define DMA2_CHANNEL4_PERIPHERAL_BASE_ADDR   0

//#define DMA2_CHANNEL5_BUFFER_SIZE   0
//#define DMA2_CHANNEL5_MEMORY_BASE_ADDR   0
//#define DMA2_CHANNEL5_PERIPHERAL_BASE_ADDR   0

//#define DMA2_CHANNEL6_BUFFER_SIZE   0
//#define DMA2_CHANNEL6_MEMORY_BASE_ADDR   0
//#define DMA2_CHANNEL6_PERIPHERAL_BASE_ADDR   0

//#define DMA2_CHANNEL7_BUFFER_SIZE   0
//#define DMA2_CHANNEL7_MEMORY_BASE_ADDR   0
//#define DMA2_CHANNEL7_PERIPHERAL_BASE_ADDR   0
/* add user code end dma define */
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

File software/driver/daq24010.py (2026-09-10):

import math
import struct
import time

import numpy as np
import serial
import serial.tools.list_ports

DEVICE_NAME = 'DAQ24010' # device 响应中的设备名特征串
BUFFER_SIZE = 8192 # 采集缓冲区的大小
EEPROM_SIZE = 256 # AT24C02 EEPROM 容量 (字节)
SAMPLERATES = (1000, 2000, 3000, 4000, 5000, 6000, 8000, 10000,
               20000, 30000, 40000, 50000, 60000, 100000, 120000, 200000) # 合法采样率 (Hz)
TRIGGER_MODES = ('software', 'level+', 'level-', 'slope+', 'slope-') # 合法触发模式

CALIB_CHANNELS = 8          # 校正参数通道数
CALIB_STRIDE = 8            # 每通道字节数 (float32 calib_k + float32 calib_b, 小端)
CALIB_BASE_ADDR = 0         # 校正参数在 EEPROM 的起始地址
CALIB_DEFAULT = (1.0, 0.0)  # 默认 (calib_k, calib_b)
CALIB_K_LIMIT = 2.0         # calib_k 允许范围 ±2
CALIB_B_LIMIT = 5.0         # calib_b 允许范围 ±5 (V)


def calib_pack(k: float, b: float) -> bytes:
    """把一阶校正参数打包为 8 字节 (float32 k + float32 b, 小端)。"""
    return struct.pack('<ff', k, b)


def calib_unpack(data: bytes) -> tuple[float, float]:
    """从 8 字节解出一阶校正参数 (calib_k, calib_b)。"""
    return struct.unpack('<ff', data)


def calib_valid(k: float, b: float) -> bool:
    """判断一阶校正参数是否有效 (有限且 |k|<=CALIB_K_LIMIT, |b|<=CALIB_B_LIMIT)。"""
    return (math.isfinite(k) and math.isfinite(b)
            and abs(k) <= CALIB_K_LIMIT and abs(b) <= CALIB_B_LIMIT)


class DAQ24010:
    """DAQ24010 八通道通用采集卡 Python 驱动。

    下位机: AT32F415 + XADC128S022 (12bit 8 通道), RS485 命令面, 无独立数据口
    (命令与数据共用同一串口)。协议为 ASCII 命令、以 CRLF 结尾、一问一答单飞行;
    采集数据经 'adc read' 以紧凑 hex 文本回传 (每样本 4 字符)。

    采集模型为"突发到 8192 点环形缓冲后自动停止", 主机需轮询取数; 受 115200
    文本 hex 链路限制, 连续吞吐上限约 2.88 kSPS。

    用法示例::

        from daq24010 import DAQ24010

        dev = DAQ24010()                 # 自动嗅探串口
        print(dev.get_device_name(), dev.get_uid())

    说明: 串口对象打开后须显式 close() 释放 (或使用 with); close() 默认会发
    reboot 强制设备复位, 使其回到干净上电态。
    """

    # ---- 串口实例 (由 __init__ 打开; pyserial Serial 对象; 关闭不置空, 用 _closed 标记) ----
    ser: serial.Serial   # 命令/数据口 (同一 RS485 串口)
    _closed = False      # 是否已 close(): 此后句柄已关, 不应再收发

    # ---- 设备参数 (由 device 命令响应刷新; 每次 get_*() 现读) ----
    device_name = None   # 设备名, 如 'DAQ24010 octo-channel-universal-daq'
    uid = None           # 24 位十六进制大写 UID; 同型号多台设备靠它区分

    # ---- 配置/状态参数 (status 命令回读缓存, 非权威; 由 get_*/set_*/get_status 刷新) ----
    channel = None            # 当前逻辑通道 1~8
    raw_rate = None           # 片外 ADC 原始采样率 Hz (100k/120k/200k)
    dec_rate = None           # 降采样输出采样率 Hz, 取值 SAMPLERATES
    trigger_mode = None       # 触发模式: software/level+/level-/slope+/slope-
    trigger_threshold = None  # 触发阈值电压 V (设备内部按 12bit 码值比较)
    avdd = None               # 当前 AVDD (ADC 基准/供电) 电压 V, 由 TL431 基准反推

    # ---- 校正参数 (初始化时从 EEPROM 载入; 8 通道, 每项 (calib_k, calib_b)) ----
    _calib = None

    # ==============================
    # 生命周期
    # ==============================

    def __init__(self, port: str | None = None, load_calib: bool = True) -> None:
        """初始化设备对象并打开串口。

        Args:
            port (str | None): 串口名 (如 'COM5'); None 则自动嗅探。
            load_calib (bool): True (默认) 从 EEPROM 载入各通道校正参数;
                False 跳过 (用于 EEPROM 尚未初始化的引导写入场景)。

        Raises:
            RuntimeError: 自动嗅探未找到 DAQ24010; 或 load_calib 且校正参数非法。
            serial.SerialException: 显式指定的串口无法打开。
        """
        explicit = port is not None
        if port is None:
            port = self._probe_port()
            if port is None:
                raise RuntimeError('cannot find any daq24010 port')
        self.ser = serial.Serial(port, 115200, timeout=1)
        if explicit and not self._validate_device():
            self.ser.close()
            self._closed = True
            raise RuntimeError(f'not a DAQ24010 device on {port}')
        if load_calib:
            self._load_calibration()   # 从 EEPROM 载入各通道校正参数

    def close(self, reboot: bool = True) -> None:
        """释放串口资源, 可重复调用 (第二次起为空操作)。

        默认先发 reboot 强制设备复位, 使其回到干净上电态 (会丢失当前
        channel/rate/trigger 配置, 但 EEPROM 内容保留); 复位成功无回包,
        故只发送不等待。句柄保持引用 (不置 None), 用 _closed 标记"已释放";
        关闭失败仅静默 (串口可能已被外部断开)。

        Args:
            reboot (bool): True (默认) 关闭前强制复位设备; False 仅关闭串口。
        """
        if self._closed:
            return
        # getattr 兜底: __init__ 中途失败被析构时字段可能尚未赋值
        ser = getattr(self, 'ser', None)
        if ser is not None:
            if reboot:
                try:
                    self.reboot()
                except Exception:
                    pass
            try:
                ser.close()
            except Exception:
                pass
        self._closed = True

    def __enter__(self) -> 'DAQ24010':
        """支持 with 语句使用: 进入 with 块时返回实例自身。"""
        return self

    def __exit__(self, *exc) -> None:
        """支持 with 语句使用: 块结束 (含异常) 自动释放串口资源。

        返回 None (假值), 使 with 块中未捕获的异常正常向外传播。
        """
        self.close()

    def __del__(self) -> None:
        """析构兜底: 对象被回收时若串口仍打开则释放。

        仅作保险, 不保证执行时机 (交互环境/循环引用下可能很晚才跑);
        确定性释放请用 close() 或 with。异常一律吞掉。
        """
        try:
            self.close()
        except Exception:
            pass

    # ==============================
    # 设备信息
    # ==============================

    def get_device_name(self) -> str:
        """读取设备名, 并刷新设备名/UID 缓存。

        现发 device 命令 (多行响应), 解析出 Name/UID 字段后存入
        self.device_name / self.uid 并返回设备名。

        Returns:
            str: 设备名, 如 'DAQ24010 octo-channel-universal-daq'。

        Raises:
            RuntimeError: 响应中不含 DEVICE_NAME 特征串 (非本设备)。
        """
        resp = self._send('device', resp_single_line=False)
        name_field, uid = self._parse_device_response(resp)
        if DEVICE_NAME not in name_field:
            raise RuntimeError(f'unexpected device response: {resp!r}')
        self.device_name = name_field
        self.uid = uid
        return self.device_name

    def get_uid(self) -> str:
        """读取设备 UID, 并刷新设备名/UID 缓存。

        现发 device 命令 (多行响应), 解析出 Name/UID 字段后存入
        self.device_name / self.uid 并返回 UID。

        Returns:
            str: 24 位十六进制大写 UID; 同型号多台设备靠它区分。

        Raises:
            RuntimeError: 响应中不含 DEVICE_NAME 特征串 (非本设备)。
        """
        resp = self._send('device', resp_single_line=False)
        name_field, uid = self._parse_device_response(resp)
        if DEVICE_NAME not in name_field:
            raise RuntimeError(f'unexpected device response: {resp!r}')
        self.device_name = name_field
        self.uid = uid
        return self.uid

    # ==============================
    # 状态查询
    # ==============================

    def get_avdd(self) -> float:
        """读取当前 AVDD (ADC 基准/供电) 电压 (status avdd 命令)。

        现发 status avdd 命令 (单行响应), 解析为浮点并刷新 self.avdd。

        Returns:
            float: AVDD 电压 (V), 由片内 TL431 基准反推。
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

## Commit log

2026-08-29 Add hardware: schematic, PCB project and Gerber
2026-08-29 Add AT32F415 firmware (Keil MDK-ARM)
2026-08-30 Add mechanical enclosure drawings
    [PCBA_Simplified.SLDASM, box.SLDPRT, daq.SLDASM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]
2026-08-30 Add box STEP export for 3D printing
    [box.STEP]
2026-09-10 fix: mark cross-ISR state volatile and guard adc read buffer
    [bsp.c, command_handler.c, global_vars.h]
2026-09-10 feat: add DAQ24010 python driver
2026-09-10 feat: add DAQ24010 calibration write script
2026-09-10 docs: mark hardware trigger as on-board verified

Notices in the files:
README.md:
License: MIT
